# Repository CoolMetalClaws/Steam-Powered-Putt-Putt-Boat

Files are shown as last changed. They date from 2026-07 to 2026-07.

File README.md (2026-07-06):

# Steam Powered Putt Putt Boat



## Overview

A 3D Printed, steam powered boat that uses parts of a drinks can to create a steam powered boiler engine for a mini putt putt boat toy. The boat is designed to run in water using a simple tealight candle. 

## Features

- Hydrodynamic design for a buoyant and fast moving boat
- Easy to assemble and requires minimal hardware
- Quick to print and assemble, using minimal time and resources
- Detachable boiler for easy assembly and ease of use
- Fully 3D printed body
- Compact steam powered watercraft
- Removable fuel supply 

## Parts

### Main Boat Body



#### A fully 3D printed body for the watercraft, allowing for a lightweight, fast-moving and buoyant design.

### Boiler Exhaust Tube



#### A propulsion tube that will be connected to a coke can boiler, providing a passage for water to propel the boat.

### Aluminum can boiler



#### A boiler made out of a used aluminum can to transmit heat to the water inside.

### Aluminum can fuel holder



#### A simple removable holder for the fuel of the boat made out of a sheet of aluminum from the can.

## 3D Printing Settings

### Material :

PLA or PETG are best suited for this project, though most fillaments should work perfectly. No specific fillaments are required. Ensure fillament is completely dry before printing to ensure part sizing and fit, as bubbling may cause an uneven surface.

### Infill : 

10% infill recommended. Less infill should be okay, but nothing below 5% infill. Recommended infill type is Gyroid or Tri-Hexagon infill for higher strength.

### Outer Walls : 

2 outer walls recommended as the part is meant to be under constant use, but cannot have excess weight.

### Supports : 

No supports are required. Please print both parts flat on bed in the orientation shown below.



## Hardware/Materials Required

### - Exacto Knife
### - Scissors
### - Masking Tape (Optional)
### - Hammmer
### - Epoxy Glue 
### - A drinks can 
### - 3D printed parts
### - Tealight Candle OR Camphor
### - Pipette (Recommended)

## BOM (Bill of Materials)

### - Epoxy Glue 

https://www.amazon.com.au/50114-ClearWeld-Quick-Setting-Epoxy/dp/B07D1NX76J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

### - Tealight Candle

https://www.google.com/aclk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

### - Camphor

https://talesofindia.com.au/products/uttam-camphor-tablets-100g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

## Assembly and Use Instructions

### 1. 

Clean up the 3D printed parts (Remove stringing if visible) and test fitting. If parts are too loose, use 1 layer of masking tape around the insertion point for a tighter fit.

### 2. 

Follow the steps below to create a boiler using a coke can and the hardware listed above.

   #### Items required:

   

   1) Cut open soda can using the exacto knife and scissors as shown in the image below. Do not discard any parts.

   

   2) Trim down sharp edges, being careful not to cut yourself. trim excess material from the concave shaped part from the base of the can.

   

   3) Using a hammer, make a concave dent on the base of the can.

   

   4) Using the input side of the boiler exhaust tube, measure out and cut a flap where the the part fits snugly. Bend flap open and tes the fit of the 3D printed exhaust tube.

   

   5) Cut a roughly sized peice of the can to seal of the bottom of the boiler. OPTIONAL: If the sheet of can continues to flex, tape down edges with masking tape to hold in place.

   

   6) Seal off all edges of the boiler with epoxy adhesive.

   7) Once the epoxy has cured partially, trim down edges.(I have temporarily used masking tape to hold the parts together, as seen in the image)

   

   8) Add the 3D printed exhaust in, with the boiler angled slightly upwards when attached to the exhaust. Use the epoxy to seal around the 3D printed exhaust, closing all gaps.

   

   9) Once the epoxy has fully set, check for leaks. If any leaks are found, use more epoxy to seal all leaks.

   10) Once the adhesive has fully set, the boiler is ready to use!

   

### 3. 

Follow the steps below to create a removable fuel holder using the remainder of the coke can and the hardware listed above.

 1) Cut the remaning sheet from soda can using the scissors as shown in the image below with the approx dimensions of 35 x 95 mm 

    

 2) Fold over the top corners, making sure not to cut yourself

    

 3) Fold in the sides of the sheet, with the bottom corners being closer. refer to the image below.

    

 4) Fold the handle part in half and angle upwards. refer to the image below.

    

 5) The Aluminum can fuel holder is ready to use!

#### 4. Fill the boiler with water using either a syringe or a pipette and connect to boat. Ensure there is a large enough gap to insert fuel so it doesn't extinguish

#### 5. Prepare fuel. fuel can be anything that can sustain a stable flame beneath the boiler. MY METHOD: Melt candle wax into cavity in the fuel holder. While the wax is still wet, press in a singular piece of camphor. 

#### 6. Place boat in water and hold in place. 

#### 7. Light fuel and place in boat, being careful not to extinguish the flame. 

#### 8. Your boat is ready! Watch it slowly putt putt away into the distance! (The boiler may take up to 3 minutes to fully heat up)

## License 

This design is under the Creative Commons Attribution-NonCommercial (CC BY-NC) licence. This design or any of its derivatives can be used only for personal use and cannot be sold. Users are free to create remixes with proper attribution to the creator, but cannot make money of them.

## Link To Original Model

https://cad.onshape.com/documents/c8c73987ce243732ea2aac3d/w/c673fa098d2116207d1ce9d8/e/dfb22e4aa31335a470dbec98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

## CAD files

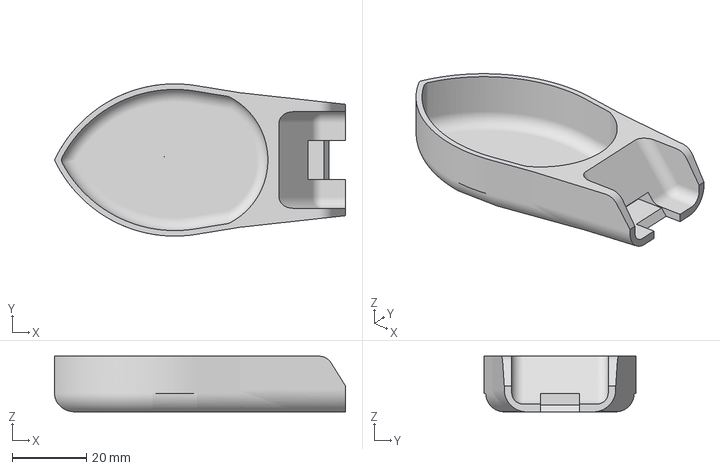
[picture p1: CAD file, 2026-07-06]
V6 Putt Putt Boat With Tealight Candle Holder (Newer Design)(Boat).3mf
78.4 x 41.0 x 15.0 mm

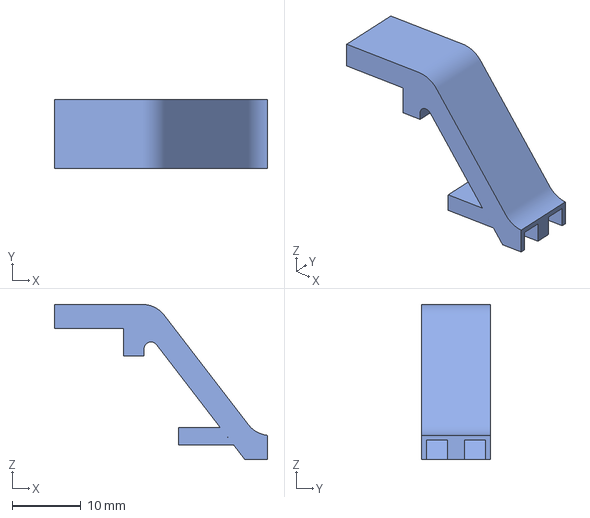
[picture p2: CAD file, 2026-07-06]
V6 Putt Putt Boat With Tealight Candle Holder (Newer Design) (Propulsion Tube).3mf
30.9 x 10.0 x 22.5 mm

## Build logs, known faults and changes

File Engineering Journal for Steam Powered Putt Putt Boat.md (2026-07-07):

# Engineering Journal for Steam Powered Putt Putt Boat

## Problem

I have always been facinated with the idea of a small portable boat that is powered by only a candle, but the commercially sold versions are expensive where i am and are often imported, taking lots of time for delivery. This made me decide i wanted to create my own version, and challenged myself to make it use the least amount of fillament and materials, utilising mostly items found in every household. This design acheives just that, and is pretty easy to make as well, allowing anyone with a 3D printer and time to spare to make it.

## Step 1: Fabricate V1-3 (1 hrs 10 mins)

Ibegan designing with a genral boat shape in mind, without keeping in mind the dimensions and sizing for the boat. This lead to boats larger than required, wasting unecessary space and creating an overall heavier design, which sometimes tended to capsize. Versions 1-3 are all models that helped me shape the final design of the model, and provided the base shape for the final version. The first 3 designs also had a weighty look, and weren't the sleek, racing-boat style that i was aiming for.

## Step 2: Adapt the design for better propulsion (2 hrs 19 mins)

The first 4 designs also did not have a propulsion channel that could output more power, and the boat was unable to move due to this. The channels also had extremely slim walls that fractured under the slightest pressure and allowed leaks to grow larger unchecked. This resulted in a loss of power in the boat, as a vaccum was not formed due to a loss of pressure, which was required to suck water back into the boiler to repeat the propulsion cycle. 

## Step 3: Designing the final version (3 hrs 20 mins)

The 5th varaint of the design was flawless, with a minor problem; the boiler was unable to detach. This caused problems during assembly, making it extremely hard to access the space beneath the boiler to check for leaks and for applying epoxy. This provided me with the idea to make the boiler and fuel source detachable. This allowed for easy assembly and servicing if something should go wrong, and made the toy easier to use and re-fuel.

## Step 4: Complete project and Write README + JOURNAL (3 hrs 28 mins)

After finalising the project, i wrote a proper, detailed README and JOURNAL to upload my completed project. The README allows anyone to recreate my putt putt boat design with easy to understand instructions and details.

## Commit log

2026-07-06 Add a README for Steam Powered Putt Putt Boat
    Added the README.md to improve formatting, add images, and enhance the description of the Steam Powered Putt Putt Boat project.
2026-07-06 Added the 3mf files for the models
    Added the 3mf files for the models to allow users to download them and create their own putt putt boat ;)
    [V6 Putt Putt Boat With Tealight Candle Holder (Newer Design) (Propulsion Tube).3mf, V6 Putt Putt Boat With Tealight Candle Holder (Newer Design)(Boat).3mf]
2026-07-07 Add engineering journal for steam-powered boat project
    Documented the engineering process and design iterations for a steam-powered putt putt boat, including challenges faced and solutions implemented.
